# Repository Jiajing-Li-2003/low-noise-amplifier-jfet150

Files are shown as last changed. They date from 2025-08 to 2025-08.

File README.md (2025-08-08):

# low-noise-amplifier-jfet150
Open source low-noise amplifier project using JFET150

# 🔊 Low-Noise Amplifier (LNA) Project – JFET150 + OPA211 + Differential Stage

This project documents the design and testing of a **low-noise amplifier (LNA)**, based on a JFET input stage followed by a precision op-amp (OPA211), and a second-stage differential amplifier.

Everything is **open source** and shared for learning, experimentation, and collaboration.

---

## 📌 Table of Contents

- [Overview](#overview)
- [Features](#features)
- [Circuit Design](#circuit-design)
- [Measurements](#measurements)
- [Bill of Materials](#bill-of-materials)
- [Schematic and PCB](#schematic-and-pcb)
- [Usage](#usage)
- [License](#license)
- [Author](#author)

---

## 🔍 Overview

This two-stage amplifier is designed for applications requiring ultra-low noise and high gain:

1. **Low-noise preamp** based on a JFET transistor (JFET150) + OPA211 with ~40 dB gain
2. **Differential amplifier** that adds another 20 dB gain and rejects common-mode noise

---

## ⚙️ Features

| Parameter | Value |
|---|---|
| Total Gain | ~60 dB (×1000) |
| Input Noise | [2 nV/√Hz, @1kHz] |
| Bandwidth | [10 Hz – 100 kHz] |
| Supply Voltage | 0V-5V |
| Input Impedance | >? MΩ |
| Output Impedance | ~??? Ω |

---

## 🔧 Circuit Design

### 🔹 Stage 1 – Low-Noise Preamp

- JFET input (JFET150)
- Precision Op-Amp (OPA211)
- Gain: ~40 dB
- Focus: low noise, high input impedance

### 🔸 Stage 2 – Differential Amplifier

- Differential op-amp topology
- Gain: ~20 dB
- Focus: common-mode noise rejection

---

## 📊 Measurements

The transfer function measurements were performed using two 20 dB attenuators, resulting in a total attenuation of 33 dB applied to the gain:

This is the transfer function of the first stage (blue curve):
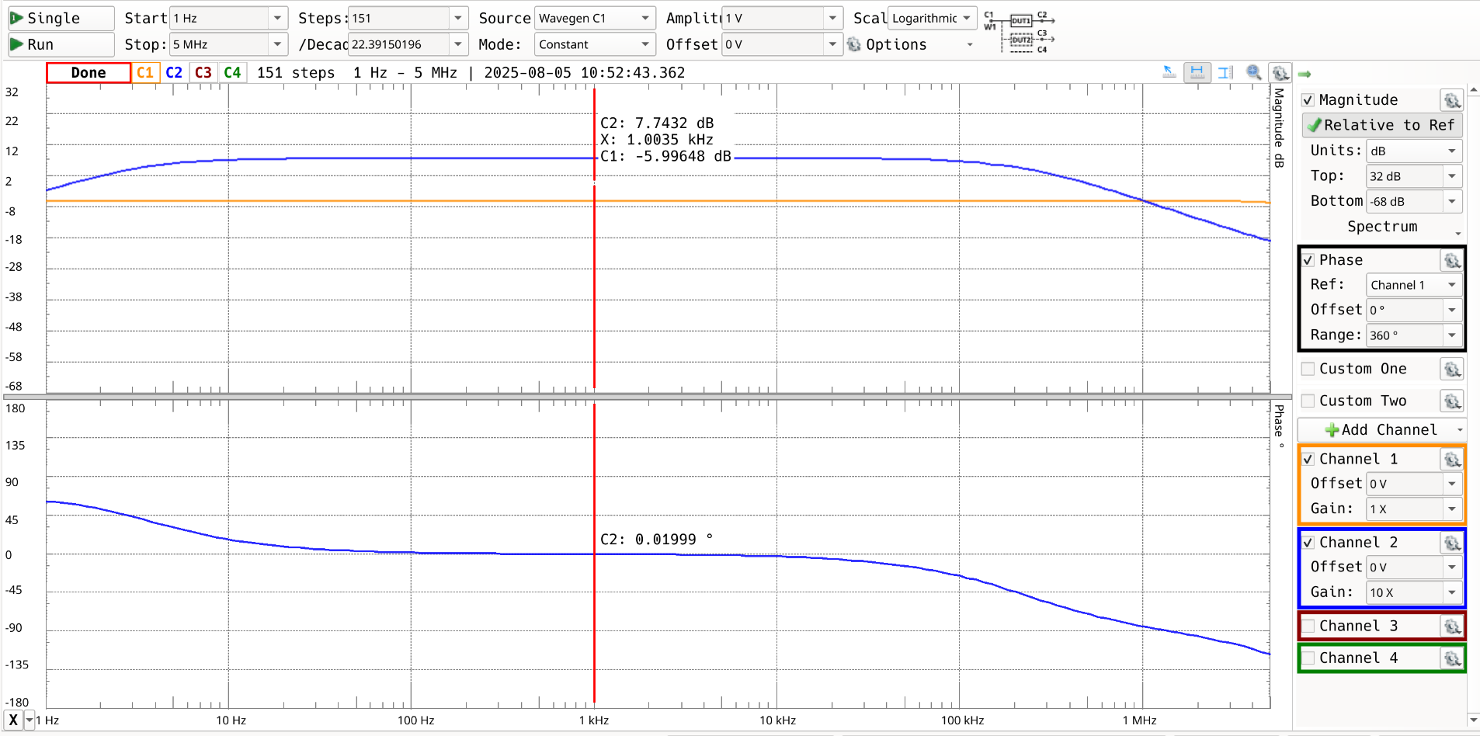
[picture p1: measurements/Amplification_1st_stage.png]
Amplification 1st stage


This is the transfer function of the second stage:
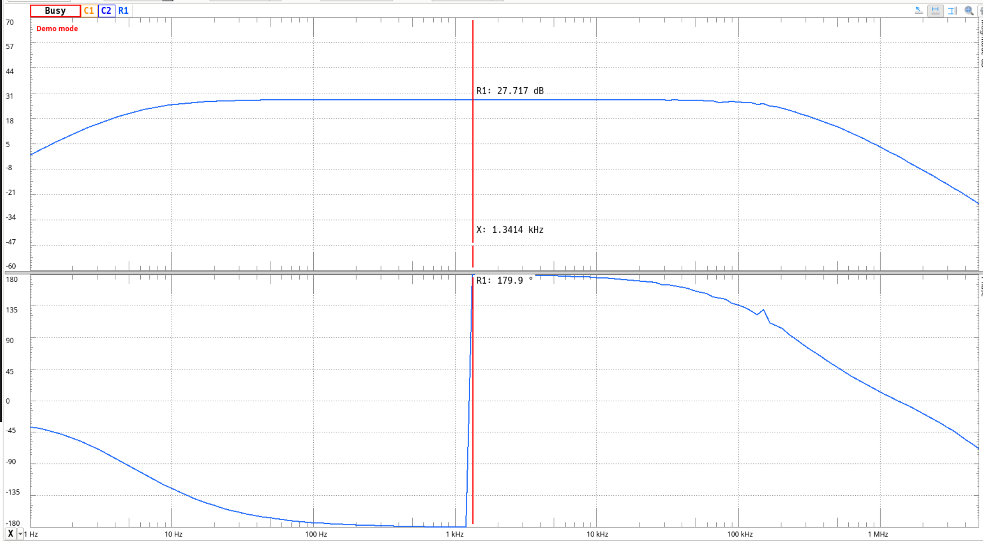
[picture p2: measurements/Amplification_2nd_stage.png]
Amplification 2nd stage


And there we have the input noise of the amplifier
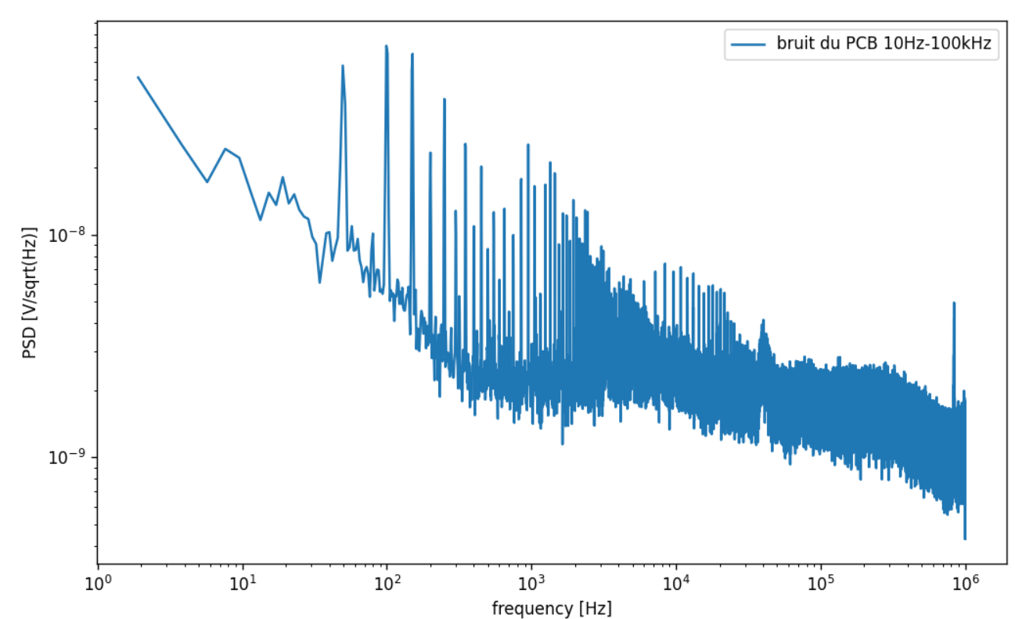
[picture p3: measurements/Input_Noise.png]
Input noise


---

## 🖨️ Schematic and PCB

Browse PCB and schematics online [here](https://kicanvas.org/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).

Files are in the `hardware/` directory.

---

## 🔌 Usage

1. **Power Supply**: +5 V regulated
2. **Input**: Search Coil (a magnetometer)
3. **Output**: Connect to oscilloscope or ADC

> ⚠️ Make sure to use a proper power supply with current limiting

---

## 🪪 License

This project is licensed under the **MIT License** – see the [LICENSE](./LICENSE) file for details.

---

## 🙋 Contributions

Feel free to fork, open issues, or submit pull requests if you want to improve or adapt this project.

---

## 👨‍🔬 Author

Designed by Li Jiajing, This project was carried out during an assistant engineer internship under the supervision of Alexis Jeandet at the Plasma Physics Laboratory (LPP).

---

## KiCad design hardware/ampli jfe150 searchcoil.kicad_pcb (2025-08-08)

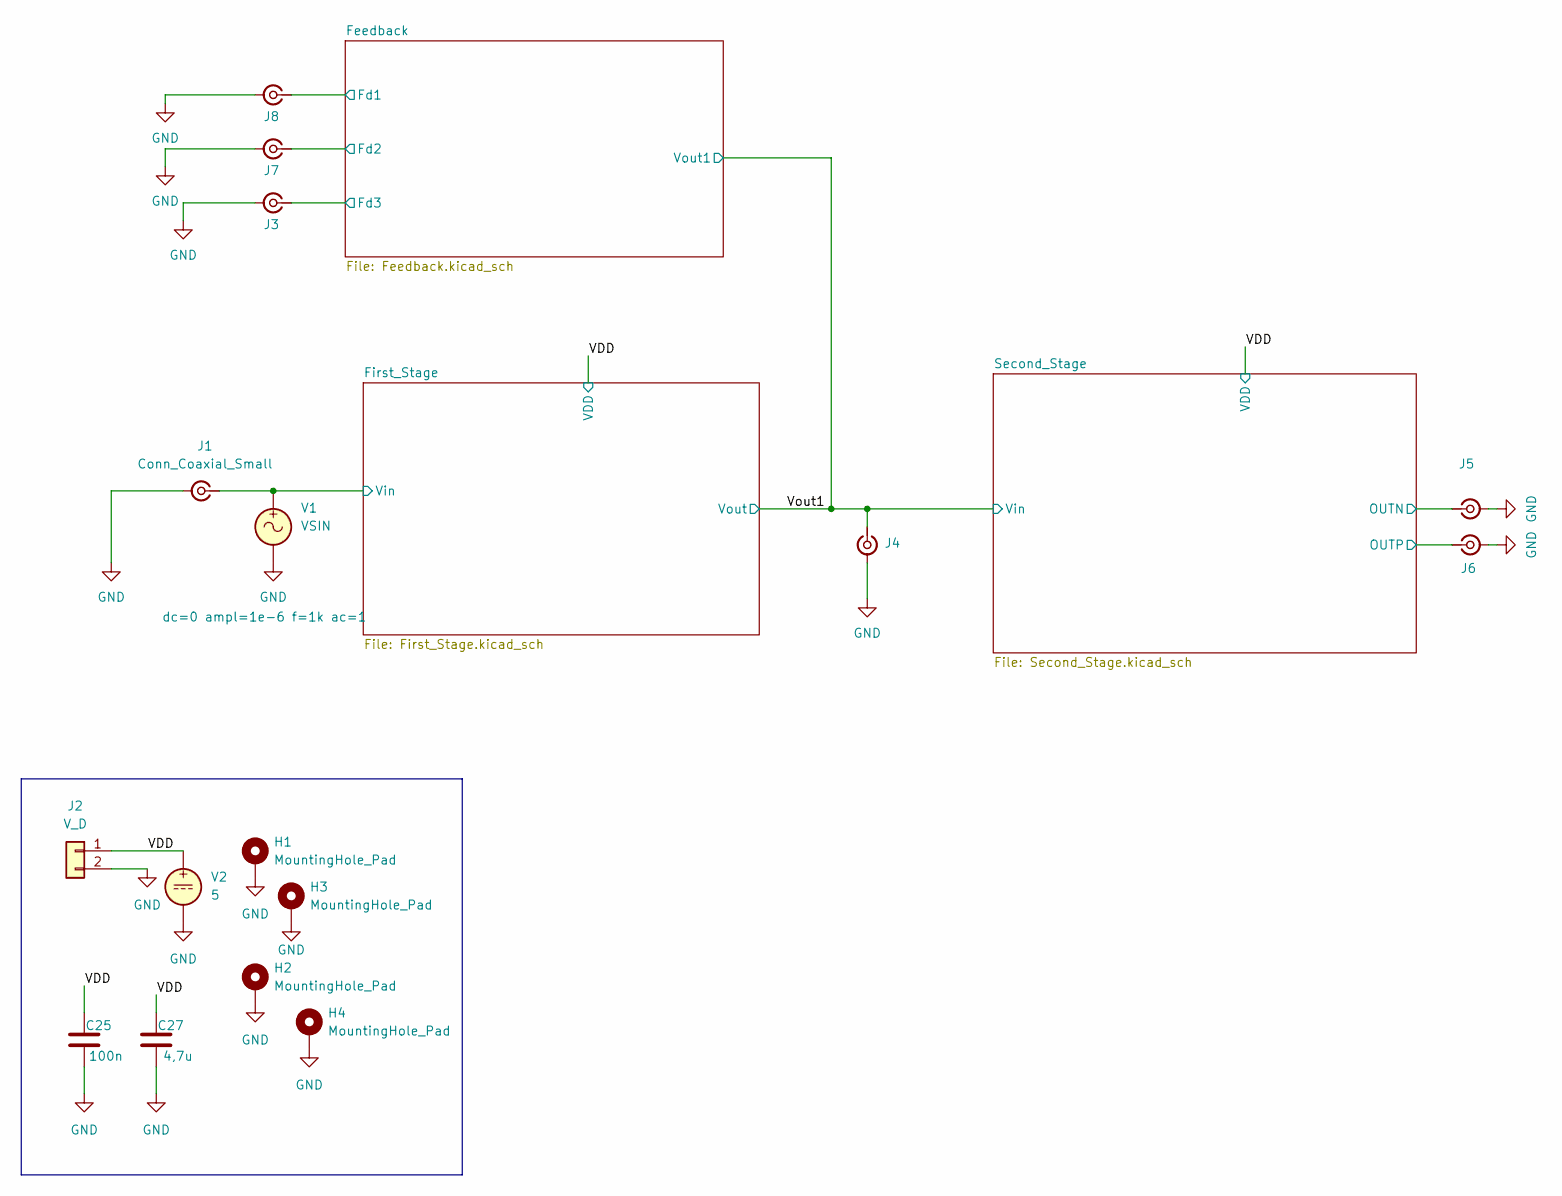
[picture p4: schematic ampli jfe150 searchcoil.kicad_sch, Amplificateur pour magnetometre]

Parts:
C25: 100n; C_0603_1608Metric_Pad1.08x0.95mm_HandSolder
C27: 4,7u; C_1206_3216Metric_Pad1.33x1.80mm_HandSolder
H1, H2, H3, H4: MountingHole_Pad; MountingHole_2.2mm_M2_DIN965_Pad
J1, J3, J4, J5, J6, J7, J8: Conn_Coaxial_Small; SMB_Jack_Vertical
J2: V_D; PinHeader_1x02_P2.54mm_Vertical
V1: VSIN
V2: 5

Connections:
/Feedback/Fd1: J8.1 (In); also elsewhere on the board
/Feedback/Fd2: J7.1 (In); also elsewhere on the board
/Feedback/Fd3: J3.1 (In); also elsewhere on the board
/First_Stage/Vin: J1.1 (In), V1.1; also elsewhere on the board
/Second_Stage/OUTN: J5.1 (In); also elsewhere on the board
/Second_Stage/OUTP: J6.1 (In); also elsewhere on the board
/VDD: C25.1, C27.1, J2.1, V2.1; also elsewhere on the board
/Vout1: J4.1 (In); also elsewhere on the board
GND: C25.2, C27.2, H1.1, H2.1, H3.1, H4.1, J1.2 (Ext), J2.2, J3.2 (Ext), J4.2 (Ext), J5.2 (Ext), J6.2 (Ext), J7.2 (Ext), J8.2 (Ext), V1.2, V2.2; also elsewhere on the board

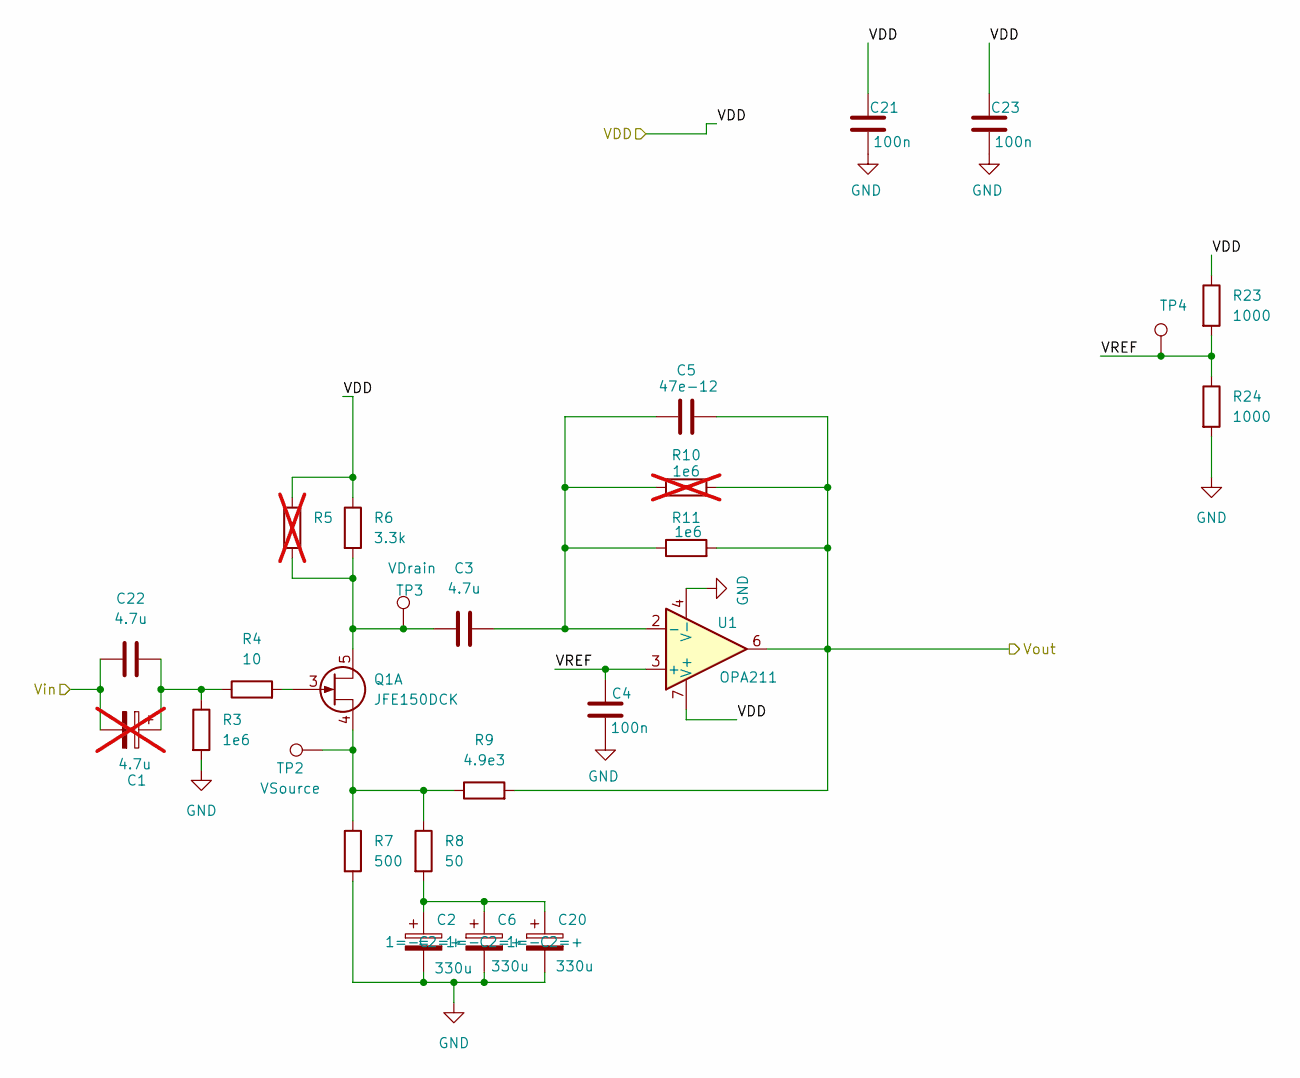
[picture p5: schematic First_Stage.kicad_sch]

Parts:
C1: 4.7u; CP_EIA-3528-21_Kemet-B_HandSolder; not fitted
C2, C6, C20: 330u; CP_EIA-6032-28_Kemet-C_HandSolder
C3, C22: 4.7u; C_1206_3216Metric_Pad1.33x1.80mm_HandSolder
C4, C21, C23: 100n; C_0603_1608Metric_Pad1.08x0.95mm_HandSolder
C5: 47e-12; C_0603_1608Metric_Pad1.08x0.95mm_HandSolder
Q1: JFE150DCK; SOT-353_SC-70-5
R3, R11: 1e6; R_0603_1608Metric_Pad0.98x0.95mm_HandSolder
R4: 10; R_0603_1608Metric_Pad0.98x0.95mm_HandSolder
R5: 10e3; R_0603_1608Metric_Pad0.98x0.95mm_HandSolder; not fitted
R6: 3.3k; R_0603_1608Metric_Pad0.98x0.95mm_HandSolder
R7: 500; R_0603_1608Metric_Pad0.98x0.95mm_HandSolder
R8: 50; R_0603_1608Metric_Pad0.98x0.95mm_HandSolder
R9: 4.9e3; R_0603_1608Metric_Pad0.98x0.95mm_HandSolder
R10: 1e6; R_0603_1608Metric_Pad0.98x0.95mm_HandSolder; not fitted
R23, R24: 1000; R_0603_1608Metric_Pad0.98x0.95mm_HandSolder
TP2: VSource; TestPoint_Loop_D1.80mm_Drill1.0mm_Beaded
TP3: VDrain; TestPoint_Loop_D1.80mm_Drill1.0mm_Beaded
TP4: 6V; TestPoint_Loop_D1.80mm_Drill1.0mm_Beaded
U1: OPA211; SOIC-8_3.9x4.9mm_P1.27mm

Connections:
/First_Stage/VREF: C4.1, R23.2, R24.1, TP4.1, U1.3 (+)
/First_Stage/Vin: C1.2, C22.1; also elsewhere on the board
/VDD: C21.1, C23.1, R5.1, R6.1, R23.1, U1.7 (V+); also elsewhere on the board
/Vout1: C5.2, R9.2, R10.2, R11.2, U1.6; also elsewhere on the board
GND: C2.2, C4.2, C6.2, C20.2, C21.2, C23.2, R3.2, R7.2, R24.2, U1.4 (V-); also elsewhere on the board
unnamed: C1.1, C22.2, R3.1, R4.1
unnamed: C2.1, C6.1, C20.1, R8.2
unnamed: C3.1, Q1.5, R5.2, R6.2, TP3.1
unnamed: Q1.3, R4.2
unnamed: Q1.4, R7.1, R8.1, R9.1, TP2.1
unnamed: C3.2, C5.1, R10.1, R11.1, U1.2 (-)

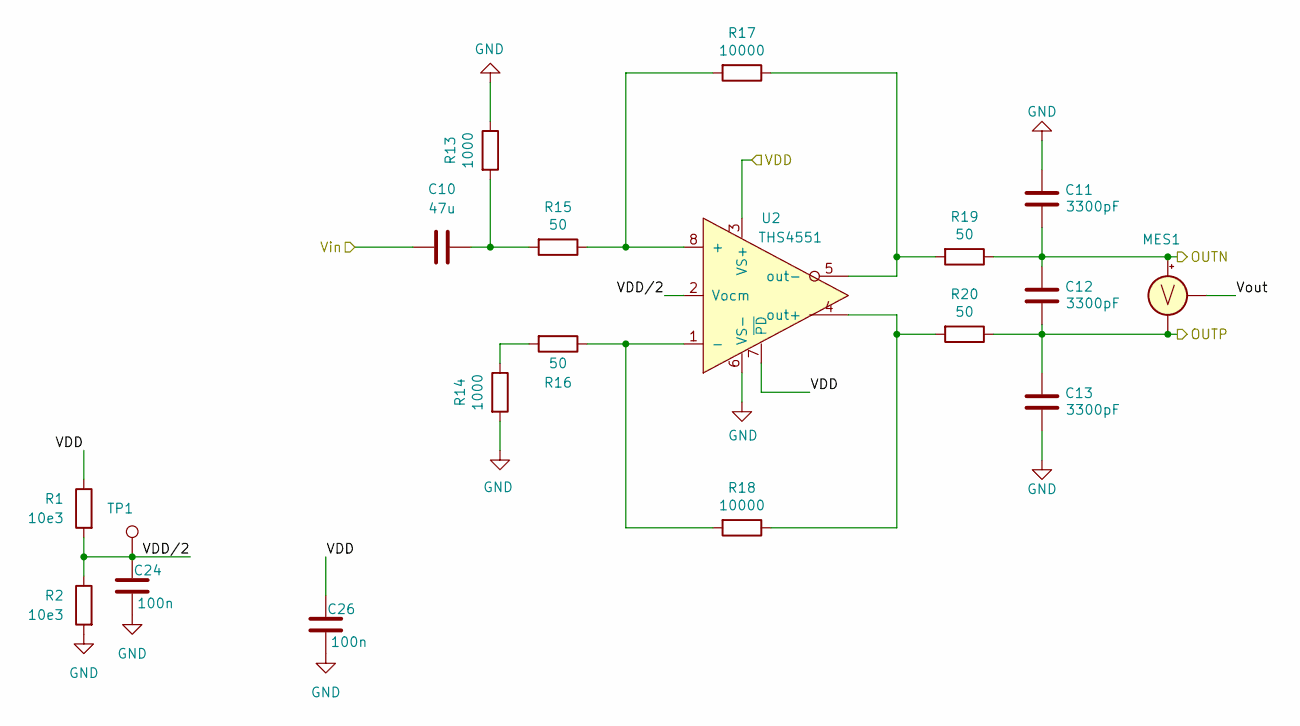
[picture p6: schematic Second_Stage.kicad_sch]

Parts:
C10: 47u; C_1206_3216Metric_Pad1.33x1.80mm_HandSolder
C11, C12, C13: 3300pF; C_0603_1608Metric_Pad1.08x0.95mm_HandSolder
C24, C26: 100n; C_0603_1608Metric_Pad1.08x0.95mm_HandSolder
MES1: VOLTMETER_DIFF
R1, R2: 10e3; R_0603_1608Metric_Pad0.98x0.95mm_HandSolder
R13, R14: 1000; R_0603_1608Metric_Pad0.98x0.95mm_HandSolder
R15, R16, R19, R20: 50; R_0603_1608Metric_Pad0.98x0.95mm_HandSolder
R17, R18: 10000; R_0603_1608Metric_Pad0.98x0.95mm_HandSolder
TP1: 6V; TestPoint_Loop_D1.80mm_Drill1.0mm_Beaded
U2: THS4551; VSSOP-8_3x3mm_P0.65mm

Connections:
/Second_Stage/OUTN: C11.2, C12.1, MES1.1 (+), R19.1; also elsewhere on the board
/Second_Stage/OUTP: C12.2, C13.1, MES1.2 (-), R20.1; also elsewhere on the board
/Second_Stage/VDD/2: C24.1, R1.2, R2.1, TP1.1, U2.2 (Vocm)
/VDD: C26.1, R1.1, U2.3 (VS+), U2.7 (~PD); also elsewhere on the board
/Vout1: C10.1; also elsewhere on the board
GND: C11.1, C13.2, C24.2, C26.2, R2.2, R13.1, R14.2, U2.6 (VS-); also elsewhere on the board
unnamed: C10.2, R13.2, R15.2
unnamed: R14.1, R16.2
unnamed: R15.1, R17.2, U2.8 (+)
unnamed: R16.1, R18.2, U2.1 (-)
unnamed: R18.1, R20.2, U2.4 (out+)
unnamed: R17.1, R19.2, U2.5 (out-)

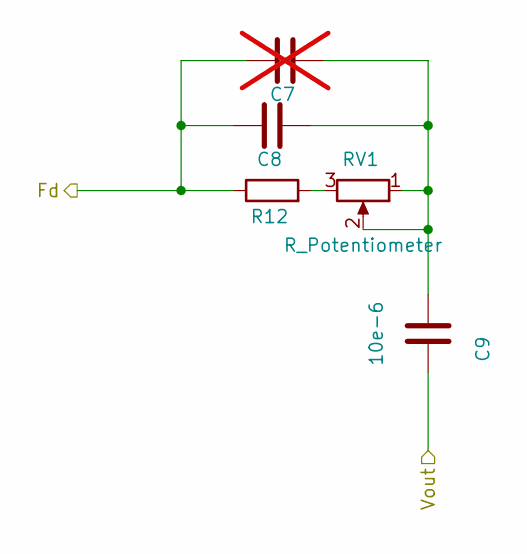
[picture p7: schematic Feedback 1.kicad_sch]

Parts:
C7: 10e-12; C_0603_1608Metric_Pad1.08x0.95mm_HandSolder; not fitted
C8: 10e-12; C_0603_1608Metric_Pad1.08x0.95mm_HandSolder
C9: 10e-6; C_1206_3216Metric_Pad1.33x1.80mm_HandSolder
R12: 10e3; R_0603_1608Metric_Pad0.98x0.95mm_HandSolder
RV1: R_Potentiometer; Potentiometer_Bourns_3296W_Vertical

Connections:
/Feedback/Fd1: C7.1, C8.1, R12.1; also elsewhere on the board
/Vout1: C9.1; also elsewhere on the board
unnamed: C7.2, C8.2, C9.2, RV1.1, RV1.2
unnamed: R12.2, RV1.3

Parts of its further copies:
C14, C17: 10e-12; C_0603_1608Metric_Pad1.08x0.95mm_HandSolder
C15, C18: 10e-12; C_0603_1608Metric_Pad1.08x0.95mm_HandSolder; not fitted
C16, C19: 10e-6; C_1206_3216Metric_Pad1.33x1.80mm_HandSolder
R21, R22: 10e3; R_0603_1608Metric_Pad0.98x0.95mm_HandSolder
RV2, RV3: R_Potentiometer; Potentiometer_Bourns_3296W_Vertical

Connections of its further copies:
/Feedback/Fd2: C14.1, C15.1, R21.1; also elsewhere on the board
/Feedback/Fd3: C17.1, C18.1, R22.1; also elsewhere on the board
/Vout1: C16.1, C19.1; also elsewhere on the board
unnamed: C14.2, C15.2, C16.2, RV2.1, RV2.2
unnamed: C17.2, C18.2, C19.2, RV3.1, RV3.2
unnamed: R21.2, RV2.3
unnamed: R22.2, RV3.3

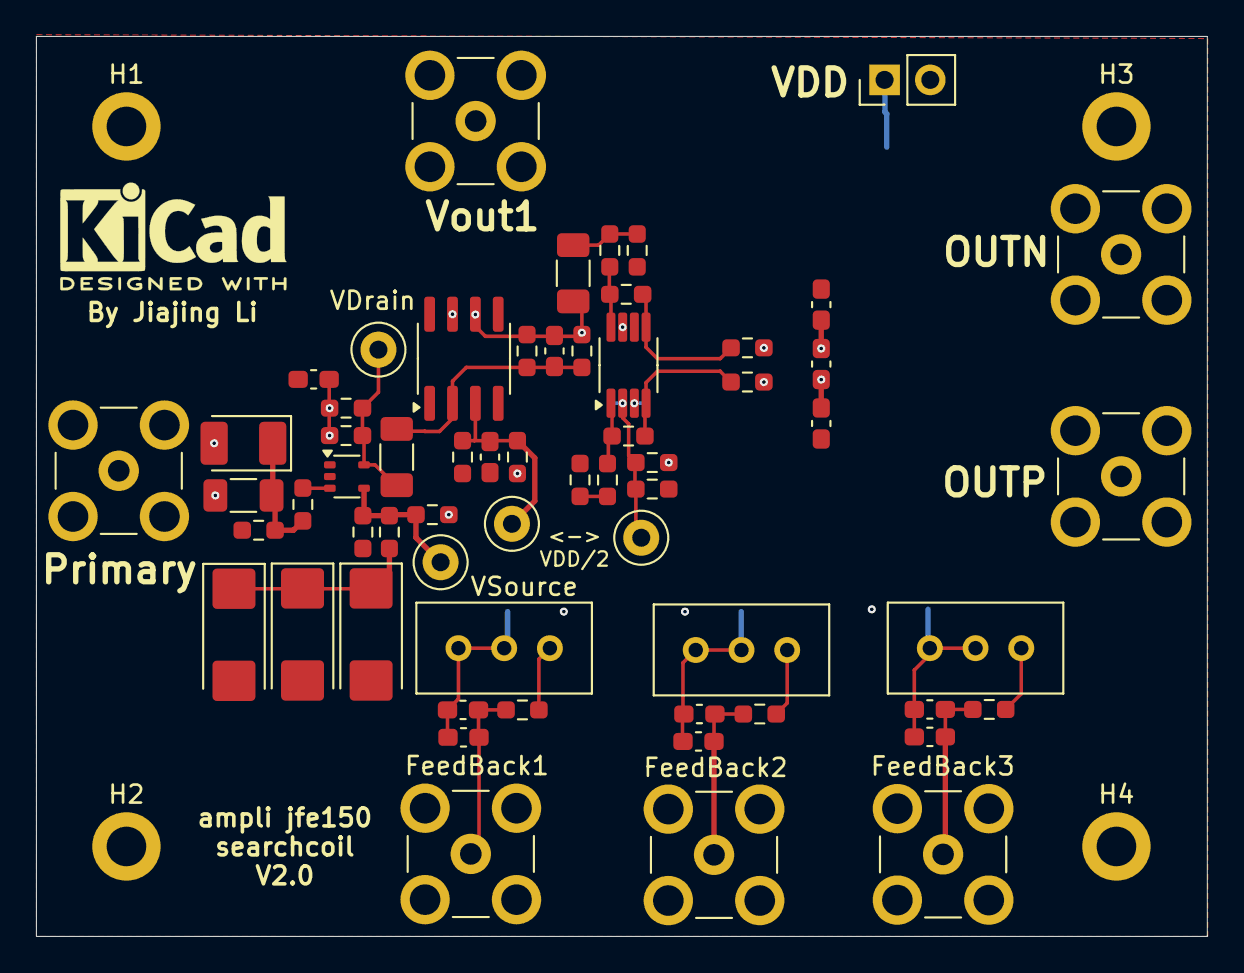
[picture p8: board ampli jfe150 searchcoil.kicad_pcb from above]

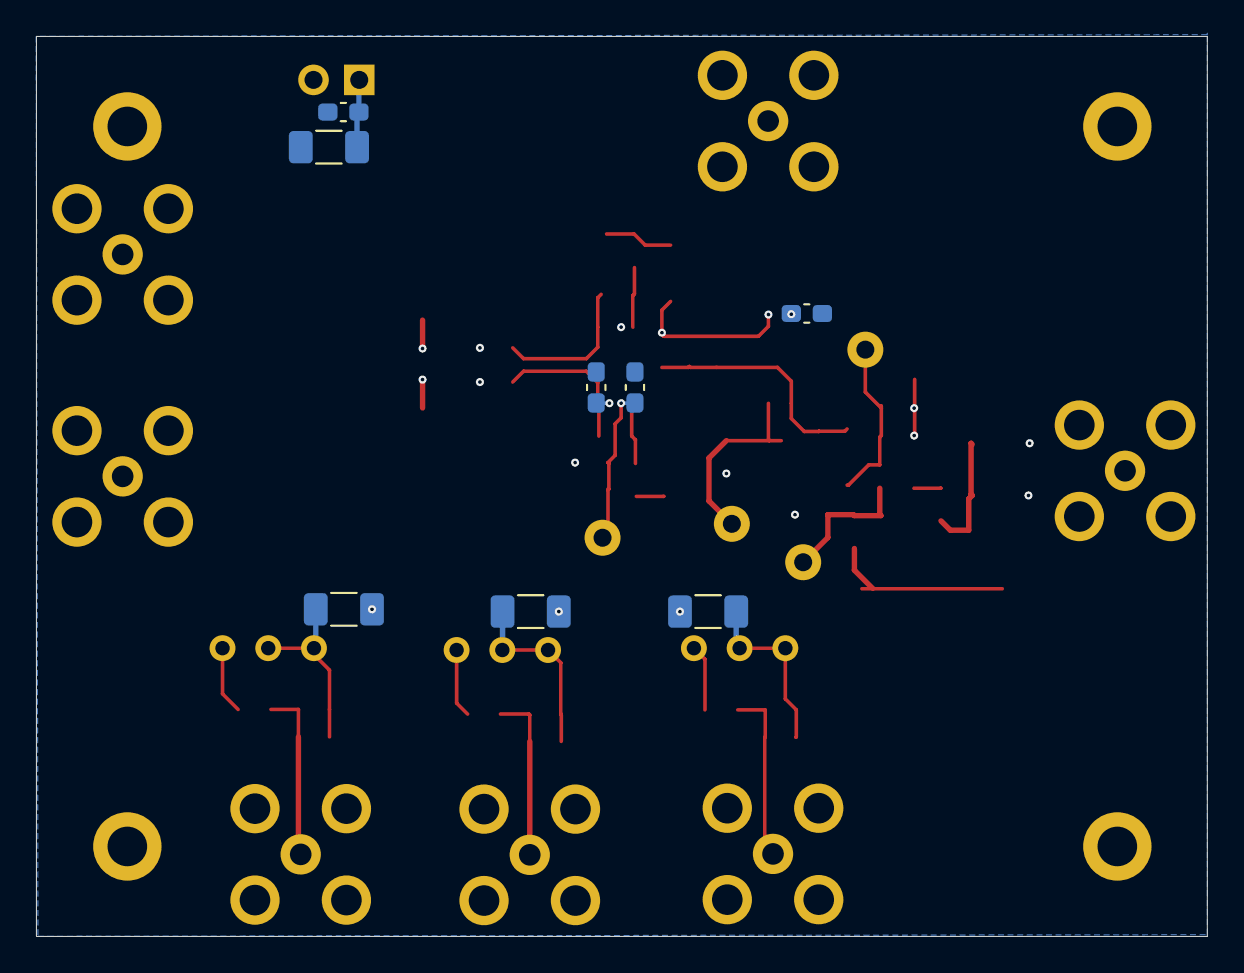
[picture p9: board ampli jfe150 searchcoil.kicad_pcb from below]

Board: 4 copper layers, 65.1 x 50.0 mm, 73 parts (8 on the bottom side), 29 nets.
